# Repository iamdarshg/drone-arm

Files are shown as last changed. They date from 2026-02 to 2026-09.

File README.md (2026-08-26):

This is a codebase that is woring to create a hardware+software solution for dron control and management in a relatively modular manner. 
This is a codebase that is woring to create a hardware+software solution for dron control and management in a relatively modular manner.
This needs to be inherenly zero-trust, zero-fail and easy to analyse statically. The langauge of choice is C, with rust and python tooling accepted as well.Follow the 10 rules as set by nasa for code, the same should apply here due to the similar no-fail environment.
Currently, the main control board has been designed and the auxiallry field-oriented control esc needs to be designed.
Ideally, as much of this code as possible should be library free and written entirely from scratch. If any libraries are used beyond standard c libararies, they should all be stored within this folder, nowehere else.
Please add as much documentation as is needed, whenevr you refer to something just download and leave it in the docs folder. Please use the pico SDK exclusively as a library for C and/or write everything using reigster level functions.
Build will occur via Meson & Ninja. This means we will be compiling the whole thing using the arm toolchain, against the headers and flash tables and such from the SDK.
When debug is enabled in the meson build, we will output the assembly instead of the .uf2 file.

## Motor Platform (selected prototype baseline)

The ESC (Rev-B) is being optimized for the **Flycci FA4119 KV350** ([product page](https://robu.in/product/flycci-fpv-brushless-motors-fa4119-350kv/)). The current prototype decision, alternatives, cost model, proposed 550 Kv rewind, selected 8x4.5 propeller and mandatory validation gates are documented in [hardware/motor_release/FA4119_PROPULSION_DECISION.md](hardware/motor_release/FA4119_PROPULSION_DECISION.md).

- 12N14P outrunner (**7 pole pairs**), stator 41x19 mm, 280 g w/ cable
- Recommended 10S-12S LiPo, 13" prop, 80 A ESC class
- Measured (12S, HQ13x9-3 3-blade): 8.18 kg max thrust / 3.47 kW max @ 48 V, 74 A battery
- A rewind to **approximately 550 kV** is the experimental target if stock-motor dyno results justify it. The chosen Orange HD 8045 propeller has no verified manufacturer RPM rating in the repository, so the 550 Kv/12S combination requires closed-loop RPM limiting and guarded testing; it is not flight-released.

### eRPM headroom

eRPM = mech RPM x pole pairs (7). At 12S max (50.4 V):

| Winding | No-load RPM | No-load eRPM | Published or initially governed loaded eRPM |
|---|---|---|---|
| 350 kV (stock) | 17,640 | ~123 k | ~77-80 k with the manufacturer's 13-inch test prop |
| 550 kV (rewind) | 27,720 | ~194 k | initially <=91 k with the 8-inch prop (13,000 mechanical-rpm ceiling) |

**280 k eRPM check:** 280 k eRPM = 4.67 kHz electrical = 40,000 mechanical RPM at 7 pole pairs. This remains a possible future bare-rotor research point, not a propeller operating point. An 8-inch prop at 40,000 RPM has approximately 426 m/s rotational tip speed before pitch velocity and is unsuitable. The proposed 550 Kv winding reaches 194 k eRPM at fully charged 12S; initial propeller testing is capped at 13,000 mechanical RPM (91 k eRPM) pending a verified rating for the exact propeller.

## Build Instructions

This project uses Meson and Ninja for building.

### Prerequisites
- [ARM GNU Toolchain](https://developer.arm.com/Tools%20and%20Software/GNU%20Toolchain) (`arm-none-eabi-gcc`)
- [Meson](https://mesonbuild.com/)
- [Ninja](https://ninja-build.com/)
- Python 3

### Configuration
Create a build directory and configure the project:
```bash
meson setup build
```

To enable **Debug Mode** (includes assembly output and `-O0`):
```bash
meson setup build -Ddebug=enabled 
```

### Building
Build the firmware:
```bash
ninja -C build
```
This produces `firmware_main_board.uf2` and `firmware_esc_module.bin` in the `build` directory.

### Testing
To build and run the unit tests:
```bash
meson test -C build
```
Current tests include:
- `test_main`: Scheduler and basic async operations.
- `test_clock_safety`: (New) Integrity protection for global clock state.
The main software will run as two non-synchronised loops- the sensor loop and the PWM loop. The one loop will run at the speed of the ESCs and will provide the best estimate for what the thrust should be at any given time to the ESCs, 60Hz if communicating via PWM and 1 kHz if communicating via SPI. This rate will be configurable. This loop may also be offloaded to the PIO modules in the future. The other loop is reponsible for sensor measuerment and fusion.

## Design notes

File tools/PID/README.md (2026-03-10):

# PID Controller Design Tool — Documentation

## Overview

This tool implements industry-standard techniques for designing and tuning PID controllers for drone pitch control, using OpenMDAO for multidisciplinary optimization. The methodology mirrors practices at aerospace companies like NASA, Boeing, and Lockheed Martin.

**Location**: `tools/PID/`
**Main Script**: `main.py`

---

## Quick Start

```bash
# Install dependencies
pip install control openmdao matplotlib numpy

# Run PID design and optimization
python tools/PID/main.py
```

**Output Files**:
- `tools/PID/comparison_plots.png` — Bode, step response, Nyquist, pole-zero comparisons
- `tools/PID/optimization_history.png` — Convergence history plots

---

## Control Theory Background

### What is a Control System?

A control system makes a system's output follow a desired reference. For a drone, we want the pitch angle to track pilot commands:

```
Reference ──►[ PID Controller ]──►┬──►[ Drone Plant ]──► Output
                                   │
                                   ▼
                                -[ Feedback ]
                                   │
                                   └────────────►
```

Where:
- **Controller C(s)**: The PID controller (what we design)
- **Plant G(s)**: The drone pitch dynamics (physics we must work with)
- **Feedback**: The measured output compared to reference

### The PID Controller Math

A PID controller produces an output based on three terms:

```
u(t) = Kp·e(t) + Ki·∫e(τ)dτ + Kd·de/dt
```

In the Laplace domain (frequency domain), this becomes:

```
C(s) = Kp + Ki/s + Kd·s = (Kd·s² + Kp·s + Ki) / s
```

**Breaking down each term (intuitively)**:

| Term | Formula | Effect | Trade-off |
|---|---|---|---|
| **Proportional** | Kp·e(t) | Response proportional to current error | Fast but leaves steady-state offset |
| **Integral** | Ki·∫e(τ)dτ | Eliminates accumulated error | Removes offset but can cause overshoot |
| **Derivative** | Kd·de/dt | Responds to error rate of change | Adds damping, reduces overshoot, noise-sensitive |

### Drone Pitch Dynamics (The Plant)

Linearizing around hover, a quadrotor's pitch dynamics follow Euler's rotation equation:

```
Ixx·θ̈ + b_damp·θ̇ = τ
```

Where:
- `Ixx` = Moment of inertia about pitch axis (kg·m²)
- `b_damp` = Aerodynamic damping (N·m·s/rad)
- `τ` = Motor torque input

Taking the Laplace transform (zero initial conditions):

```
Ixx·s²·Θ(s) + b_damp·s·Θ(s) = T(s)
G(s) = Θ(s)/T(s) = 1 / (Ixx·s² + b_damp·s)
```

This is a **second-order system** with a pole at `s = 0` (integrator) and a pole at `s = -b_damp/Ixx` (damping).

### Closed-Loop Transfer Function

With unity feedback H(s) = 1:

```
T(s) = L(s) / (1 + L(s))   where   L(s) = C(s)·G(s)
```

The closed-loop transfer function describes how output responds to reference changes. The **poles** of T(s) (roots of the denominator) determine system behavior:
- Poles in left half-plane (LHP) = stable
- Distance from origin = speed (rise time)
- Angle from negative real axis = overshoot tendency

---

## Stability Analysis

### What Makes a System Stable?

A linear system is stable if all poles have negative real parts (left half of the complex plane). Unstable systems oscillate with growing amplitude.

### Gain Margin (GM)

**Definition**: How much the loop gain can increase before the system becomes unstable.

**How to find it**:
1. Find the **phase crossover frequency** ω_pc where phase of L(jω) = -180°
2. Measure gain at that frequency
3. GM = 1 / |L(jω_pc)|, expressed in dB

**Industry standard**: GM ≥ 6 dB for aerospace applications

### Phase Margin (PM)

**Definition**: How much phase lag can be added before instability.

**How to find it**:
1. Find the **gain crossover frequency** ω_gc where |L(jω)| = 1 (0 dB)
2. Measure phase at that frequency
3. PM = 180° + ∠L(jω_gc)

**Industry standard**: PM ≥ 45° for aerospace applications

### Intuition

Think of a swing:
- **Gain margin**: How much harder you can push before losing control
- **Phase margin**: How much delay you can tolerate before the swing goes chaotic

Both margins provide **robustness** against modeling errors and parameter variations.

---

## The Optimization Problem

Tuning PID gains manually is difficult. We formulate it as a **constrained optimization problem**:

### Design Variables
- Kp ∈ [0.1, 50]
- Ki ∈ [0, 20]
- Kd ∈ [0, 10]

### Objective Function
```
Minimize: J = settling_time + 0.05 × overshoot_pct
```

The weight 0.05 means "1% overshoot is worth 0.05s of settling time" — balancing speed and overshoot.

### Constraints
- **Gain Margin**: GM ≥ 6 dB (robustness requirement)
- **Phase Margin**: PM ≥ 45° (robustness requirement)

### Why OpenMDAO?

OpenMDAO is NASA's open-source MDO framework used throughout the aerospace industry:
- Handles constrained optimization with gradients
- Provides convergence analysis
- Separates analysis (control theory) from optimization (numerical methods)
- Industry-proven reliability

---

## Step Response Metrics

When we apply a step input (instantaneous reference change), the response tells us about controller performance:

| Metric | Definition | Typical Desired Value |
|---|---|---|
| **Rise Time** | Time from 10% to 90% of final value | Fast |
| **Settling Time** | Time to stay within 2% of final value | < 0.5s for drone pitch |
| **Overshoot** | How much response exceeds final value | < 10% typically |
| **Steady-State Error** | Final value minus reference | 0 (ideally) |

---

## File Structure

```
tools/PID/
├── README.md          # This file
├── main.py            # Main orchestrator, OpenMDAO component, plots
├── drone_model.py     # Drone pitch dynamics model
└── TODO.md            # Development notes
```

### `main.py` Components

1. **DronePitchModel** class: Pitch dynamics G(s) and PID controller C(s)
2. **PIDPerformanceComp**: OpenMDAO component computing metrics
3. **analyze_with_gains()**: Complete system analysis function
4. **plot_*** functions: Visualization of Bode, step, Nyquist, poles
5. **create_optimization_problem()**: OpenMDAO problem setup
6. **main()**: Orchestrator running the full workflow

### `drone_model.py` Components

1. **DronePitchModel** dataclass: Physical parameters (Ixx, b_damp)
2. Transfer function creation methods
3. Stability margin analysis
4. Step response metrics

---

## Troubleshooting

### Optimization Fails to Converge
- Initial gains may be in a poor region
- Try different initial values
- Check if constraints are too tight

### Gain/Phase Margins Show "inf"
- Phase never reaches -180° or gain never reaches 0 dB
- System is "very stable" in that sense
- Clamped to 60 dB / 90° in code

### Plots Show No Data
- Check matplotlib backend: `matplotlib.use('TkAgg')` if needed
- Ensure all dependencies installed

---

## References

1. **OpenMDAO Documentation**: https://openmdao.org/
2. **Python Control Library**: https://python-control.readthedocs.io/
3. **NASA MDO Practices**: https://ntrs.nasa.gov/api/citations/20180004467/downloads/20180004467.pdf

---

## Next Steps

To integrate with actual drone firmware:
1. Export optimized Kp, Ki, Kd values
2. Implement discrete-time PID in C (use bilinear/Tustin transform)
3. Add anti-windup logic for integral term
4. Test on hardware with safety limits

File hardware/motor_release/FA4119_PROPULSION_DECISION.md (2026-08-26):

# FA4119 Propulsion Decision Record

Status: **selected prototype baseline; not yet flight-released**

Decision date: 2026-08-26

Applies to: four-motor, 12S propulsion prototype

## 1. Decision

Use four Flycci FA4119 outrunners as the motor platform instead of manufacturing
the previously proposed stator, rotor bell, magnet carrier, shaft and bearing
system from first principles.

The purchased motor is the FA4119 KV350:

- 12 slots / 14 poles (7 pole pairs)
- 41 mm stator OD x 19 mm active stack
- approximately 50.5 mm motor OD x 44 mm height
- approximately 280 g including cable
- stock 350 rpm/V winding
- manufacturer recommendation: 10S-12S, 80 A ESC, 13-inch propeller
- manufacturer-published 12S-class point: approximately 3.47 kW, 74 A,
  11,256 rpm and 8.18 kgf using an HQ 13x9 three-blade propeller

The intended experimental variant is a **sensorless rewind to approximately
550 Kv**, operated from 12S with an Orange HD 8045 (8x4.5) CW/CCW propeller.
This combination is a development target, not a validated operating point.
The stock 350 Kv winding remains the lower-risk first-article baseline and
must be dyno-tested before a rewind is authorized for all four units.

No Hall-effect sensors are required. Rotor position is estimated by the ESC.

## 2. Requirements that drove the selection

The final system-level constraints used in this decision are:

| Requirement | Current value |
| --- | --- |
| Motors | 4 |
| Battery | 12S LiPo, 44.4 V nominal, 50.4 V fully charged |
| Desired nominal input per motor | approximately 2.7 kW |
| Desired current point | approximately 60 A at nominal 12S |
| Burst duration under discussion | up to 50 s at approximately 2.7 kW; requires test validation |
| Aircraft mass | approximately 8 kg |
| Desired total static thrust | aspirational 20 kgf; not yet demonstrated |
| Propeller packaging | ultimately moved from 5.5-7 inch concepts to an 8x4.5 candidate |
| Controller | sensorless FOC; current, RPM and temperature limiting required |

At nominal 12S, 60 A corresponds almost exactly to the desired input power:

```text
44.4 V x 60 A = 2.664 kW
```

At maximum charge, the same current is 3.024 kW. The FA4119's published
3.47 kW / 74 A test makes it the only retail candidate considered in this
thread with evidence near the required electrical power. That evidence does
not validate the rewind or the 8-inch propeller.

## 3. Alternatives considered

### 3.1 Fully custom 12-slot / 8-pole motor

The custom route evolved through several geometries, including a 42 mm stator
OD, approximately 20 mm stack, 62 mm motor OD, 45 mm height, 8 mm shaft,
retail block magnets, a formed 0.5 mm mild-steel flux liner, carbon/glass
retention, and machined 6061-T6 end components.

It was rejected as the primary prototype route because it required all of the
following to be solved simultaneously:

- retail electrical-steel or destructive donor-core sourcing
- lamination punching and interlaminar insulation
- a new high-speed rotor and magnet-retention system
- unverified retail magnet grade and temperature capability
- composite process qualification and rotor overspeed testing
- high-speed bearing qualification
- corrected manufacturing CAD, tolerance drawings and CNC quotations
- coupled electromagnetic, thermal, mechanical and harmonic validation

The custom artifacts remain useful research, but they are superseded for the
current prototype. They must not be mixed with the FA4119 BOM.

### 3.2 Three REES52 5010-class donors per motor

This route attempted to combine multiple inexpensive donor stacks to obtain
the desired active length. It required 12 donor motors for four propulsion
units and still retained a custom rotor, magnets, liner, shaft and end cap.
The material and integration cost approached that of a more suitable complete
motor while preserving most of the technical risk. It was rejected.

### 3.3 Axisflying AZ3115/AZ3215 900 Kv

Advantages:

- approximately 900 Kv already close to the earlier 800-840 Kv target
- comparatively inexpensive
- no major rewind needed for that Kv region

Reasons rejected for the final 12S platform:

- nominally a 3S-6S motor
- published power approximately 1.6-1.74 kW, below the 2.7 kW target
- published thrust approximately 4.1 kgf with a much larger 9-10 inch prop
- stock rotor not qualified for 12S no-load speed

### 3.4 Tarot 5008 340 Kv

The Tarot has a large diameter but only an approximately 8 mm active stack and
about a 700 W published power level. Raising it from 340 Kv to the earlier
800 Kv target would require a severe turn-count reduction while retaining a
core designed for low-speed 17-18 inch props. It was rejected.

### 3.5 Flycci FA4119 350 Kv

Selected because its 41x19 mm stator is almost exactly the desired compact
core, the complete motor fits the 62 mm OD / 45 mm height packaging envelope,
and its published 12S test exceeds the desired per-motor power. Buying the
complete motor removes the need to fabricate the rotor, back iron, magnets,
shaft, bearing system and housing for the first prototype.

## 4. Why the topology is now 12N14P

The selected motor is 12-slot / 14-pole. Rewinding changes turns, conductor
area, resistance, inductance, termination and Kv; it does **not** change rotor
pole count. Converting the FA4119 to the previously discussed 8-pole topology
would require a new rotor and would defeat most of the reason for selecting a
complete retail motor.

For this release:

```text
pole pairs = 14 / 2 = 7
electrical RPM = mechanical RPM x 7
electrical frequency (Hz) = mechanical RPM x 7 / 60
```

## 5. Winding decision

### 5.1 Stock first article

Purchase one FA4119 first and record, before destructive unwinding:

1. Stock no-load Kv at a safe low voltage.
2. No-load current versus speed.
3. Line-to-line resistance corrected to 25 C.
4. Line-to-line inductance at 1 kHz and 10 kHz.
5. Star or delta termination.
6. Turns per tooth, winding direction and phase sequence.
7. Strand count and bare/enamelled strand diameter.
8. Removed copper mass and usable slot fill.
9. Back-EMF waveform and phase balance.

The other three motors must not be unwound until the first article produces a
repeatable winding and passes the guarded dyno sequence.

### 5.2 Nominal 550 Kv target

If magnetic flux and termination are unchanged, turns scale approximately
inversely with Kv:

```text
N_550 / N_350 = 350 / 550 = 0.636
```

The 550 Kv winding therefore requires approximately 63.6% of the stock
effective series turns. Integer turns determine the actual Kv, so 550 is a
target, not a value to print on the motor before spin measurement.

If the stock winding is star-connected, a star/delta change alters Kv by
approximately sqrt(3) and must be included before choosing the turn count.
The freed slot area must be used for additional parallel copper so that phase
resistance and current density remain controlled.

Only Class-H or better enamelled winding copper is acceptable. Nomex slot
liners and compatible impregnation varnish remain in the rewind BOM. Building
wire, speaker wire, bare copper strips with many joints, and PVC/nylon-insulated
conductors are not approved winding substitutes.

## 6. 12S speed envelope

The theoretical no-load values are:

| Winding | 44.4 V nominal | 50.4 V maximum | Maximum no-load eRPM |
| --- | ---: | ---: | ---: |
| Stock 350 Kv | 15,540 rpm | 17,640 rpm | 123,480 eRPM |
| Proposed 550 Kv | 24,420 rpm | 27,720 rpm | 194,040 eRPM |

The earlier 40,000 mechanical-rpm discussion corresponds to 280,000 eRPM and
4.67 kHz electrical frequency. It may be retained as a future bare-rotor
research point, but it is not an operating target for an 8-inch propeller.

## 7. Selected propeller and unresolved rating

Candidate: Orange HD 8045, 8x4.5, one CW and one CCW per pair:

<https://robu.in/product/orange-hd-propellers-80458x4-5-carbon-fiber-props-1cw1ccw-1pair-black/>

The retail title calls it carbon fibre, while comparable listings describe an
8045 carbon-nylon propeller. No manufacturer-issued maximum-RPM certificate
for the exact item was found. It must therefore be treated as an **unrated
multirotor propeller**, not as a continuous-laminate carbon racing propeller.

For reference, APC's published category limits are:

```text
multirotor: 105,000 / diameter_in = 13,125 rpm for 8 inches
durable FPV: 150,000 / diameter_in = 18,750 rpm for 8 inches
racing electric: 270,000 / diameter_in = 33,750 rpm for 8 inches
```

These formulas apply to APC's own qualified categories and do not certify the
Orange prop. Until written evidence is obtained, the initial hard ceiling is
13,000 mechanical rpm.

Eight-inch rotational tip speeds are:

| Speed | Tip speed | Approximate Mach at sea level |
| --- | ---: | ---: |
| 13,000 rpm | 138 m/s | 0.40 |
| 17,640 rpm | 188 m/s | 0.55 |
| 18,750 rpm | 199 m/s | 0.58 |
| 27,720 rpm | 295 m/s | 0.86 |
| 40,000 rpm | 426 m/s | 1.24 |

The values exclude axial/pitch velocity. Unrestricted 550 Kv operation on a
fully charged 12S pack is therefore not approved with this propeller.

## 8. Required controller limits

A throttle percentage limit alone is not sufficient because an unloading,
damaged or detached propeller lets the motor accelerate toward no-load speed.
The sensorless FOC controller must use measured/estimated RPM plus current and
temperature feedback.

Initial first-article limits:

| Limit | Initial value |
| --- | ---: |
| Soft RPM rollback | 12,500 mechanical rpm |
| Hard RPM shutdown | 13,500 mechanical rpm |
| Soft battery-current rollback | 55 A |
| Hard battery-current limit | 60-65 A |
| Winding-temperature rollback | 100-110 C |
| Winding-temperature shutdown | 120 C during development |
| Bell/magnet-region warning | 70 C |
| Bell/magnet-region shutdown | 80 C pending magnet/adhesive data |

Only after the exact propeller obtains a suitable rating and guarded dyno
testing passes may a second profile be considered:

| Limit | Provisional upper profile |
| --- | ---: |
| Soft RPM rollback | 17,000 mechanical rpm |
| Hard RPM shutdown | 18,000 mechanical rpm |
| Nominal current limit | 60 A |
| Short overcurrent ceiling | 70-75 A, subject to thermal data |

The ESC must support at least 200,000 eRPM with margin, 12S maximum voltage,
sensorless FOC, RPM telemetry/governing, current limiting and thermal rollback.

## 9. Cost decision for four motors

Confirmed motor price: INR 4,500 each.

| Item | Four-motor estimate |
| --- | ---: |
| Four FA4119 motors | INR 18,000 |
| Rewind copper, Nomex, varnish, thermistors and small consumables | approximately INR 7,000 |
| Motor plus rewind subtotal | **approximately INR 25,000** |
| Previously selected composite order | INR 4,271 |
| Vacuum pump for infusion | INR 6,800 |
| Motor, rewind, composite order and pump | **approximately INR 36,071** |

Two propeller pairs, ESCs, shipping, taxes not included in the confirmed motor
price, and replacement test articles must be added. If the stock 350 Kv
winding is retained, approximately INR 6,900 of rewind materials can initially
be deferred.

The FA4119 path removes these custom-motor purchases from the active BOM:

- separate rotor magnets
- formed mild-steel rotor liner
- custom rotor carbon/glass sleeve
- custom 6061 rotor end cap and stator carrier
- separate 8 mm shaft stock
- separate 608 bearings
- Hall-effect sensors
- donor motors or donor laminations

## 10. Verification and release gates

No claimed thrust, aircraft speed, efficiency or 50-second burst value is a
release fact until measured with the exact winding and propeller.

The minimum sequence is:

1. Characterize one untouched stock motor.
2. Balance the stock bell and each propeller independently.
3. Dyno the stock 350 Kv motor with the selected prop behind containment.
4. Test at 8,000, 10,000, 12,000 and 13,000 rpm while logging voltage,
   current, input power, RPM, thrust, torque, winding temperature, bell
   temperature, ESC temperature and vibration.
5. Inspect the prop hub, blades, shaft, bell, magnets and bearings after every
   step.
6. If the stock configuration cannot meet the measured aircraft requirement,
   rewind only the first article to the calculated 550 Kv winding.
7. Measure actual Kv, resistance, inductance, no-load current and phase balance.
8. Repeat the guarded propeller ladder at the initial limits.
9. Run 2-minute thermal characterization at lower current before attempting
   the requested 50-second 2.7 kW burst.
10. Perform a propeller-free overspeed test in a rated containment fixture;
    do not infer rotor proof from a propeller test.
11. Freeze winding turns/strand count only after two repeat builds correlate.
12. Flight release requires four matched motors and props plus aircraft-level
    loss-of-prop, ESC fault, vibration and EMI testing.

## 11. Superseded documents

The following release-package files describe an older custom motor and remain
only for traceability:

- `MOTOR_SPECIFICATION.md`
- `materials.md`
- `magnet_specification.md`
- `bearing_specification.md`
- `tolerances.md`
- custom STEP, DXF, drawing, winding and optimizer artifacts in this directory
- `FINAL_BOM_4_MOTORS_EXCL_STATOR_CORE.md` and its CSV counterpart

They are not manufacturing instructions for the FA4119 prototype. This
decision record is the current propulsion baseline until measured first-article
data supports a revised release.

## 12. External references

- Flycci FA4119 manufacturer data:
  <https://www.flyccimotor.com/fa4119-brushless-motor-product/>
- Robu FA4119 retail listing:
  <https://robu.in/product/flycci-fpv-brushless-motors-fa4119-350kv/>
- Selected Orange HD 8045 retail listing:
  <https://robu.in/product/orange-hd-propellers-80458x4-5-carbon-fiber-props-1cw1ccw-1pair-black/>
- APC category RPM limits used only as reference:
  <https://www.apcprop.com/technical-information/rpm-limits/>

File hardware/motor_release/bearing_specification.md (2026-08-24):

# Bearing Specification

## Arrangement

- Front (prop end): **6901-2RS** thin-section deep groove, 12x24x6 mm, radially supports the prop overhung load and all axial thrust.
- Rear: **685-2RS** extra-thin-section, 5x11x3 mm (or 688 if shaft stiffness review requires), locates the rotor axially at the cold end.
- Both bearings pressed onto ground shaft seats and clamped in machined aluminum housings with a light axial preload wave washer at the rear.

## Loads and life

| Load case | Front bearing | Rear bearing |
| --- | --- | --- |
| Prop thrust 45 N axial | carries fully | negligible |
| Rotor weight plus 1g maneuver ~10 N radial | majority | remainder |
| Residual unbalanced magnetic pull (10% of mean gap attraction) | shared by span | shared by span |

L10 basic rating life target: at least 2000 h at design point loads and 13,300 rpm.
Grease: high-speed synthetic polyurea or ester, suitable to 25,000 rpm DN
envelope. -2RS contact seals retained; shielded (-ZZ) alternate only with a
manufacturer-approved relubrication plan.

## Installation

- Shaft seat tolerances per tolerances.md; housing bores H7.
- Assembly by pressing on the inner ring only; never transmit force through balls.
- Maximum assembly heating temperature for bearings: 110 C.

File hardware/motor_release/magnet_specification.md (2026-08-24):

# Permanent Magnet Specification

## Grade and geometry

- Material: sintered NdFeB, grade **N42SH** (Br = 1.24-1.30 T design window; the optimizer used 1.244 T)
- SH temperature class: max continuous operating temperature 150 C, with intrinsic coercivity Hcj >= 20 kOe retained to that temperature
- Magnet radial thickness: 6.5 mm
- Pole count: 8 (arc-pitched to give approximately 0.85 pole arc to pole pitch ratio)
- Axial length: 56.0 mm (matches stator stack)

## Thermal and demagnetization verification

- Continuous thermal FEM gives magnet-region temperature <= 113.5 C at 45 C ambient with 60 A continuous: 36.5 C of margin to the SH 150 C limit.
- Burst case (90 A / 30 s) transient adds under 15 C: still at least 20 C of margin.
- Demagnetization check: peak armature reaction at 90 A burst keeps the operating point above the knee for N42SH at 130 C; manufacturer to confirm with FEA of the final magnet shape.

## Retention

1. Bond line: structural epoxy, 0.10 mm nominal, cured per adhesive datasheet.
2. Mechanical backup: 0.5 mm minimum steel retaining ring or bell lip crimp designed for hoop stress at 16,659 rpm proof speed with safety factor >= 2 against ring yield.
3. Balance: rotor assembly balanced to ISO 21940 G6.3 after magnet installation.

## Acceptance

- Each magnet batch certified for Br, Hcj, and SH-class temperature coefficient.
- Sample pull test: bond plus retention system survives 1000x centrifugal equivalent acceleration at room temperature on a spin fixture.

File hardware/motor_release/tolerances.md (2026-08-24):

# Tolerances And Critical Fits

## General

- Unspecified dimensions: ISO 2768-m (medium).
- All rotating parts balanced after final assembly: ISO 21940 G6.3 at rated speed.

## Critical fits

| Feature | Fit / tolerance | Rationale |
| --- | --- | --- |
| Stator OD to housing bore | H7/g6 press with adhesive | heat transfer and torque reaction |
| Lamination stack length | 56.0 (+0.3 / -0.0) mm | axial magnet-stator alignment |
| Bearing shaft seats | k5 | standard rotating inner ring fit |
| Bearing housing bores | H7 | outer ring clearance fit with clamp |
| Prop adapter thread | M8x1.25 6H/6g, or per prop spec | clamped, not keyed |
| Shaft runout at prop seat | <= 0.02 mm TIR | vibration limit |
| Air gap (nominal 0.50 mm) | concentricity budget keeps local gap >= 0.35 mm | avoids pull-in under UMP |
| Magnet pocket depth | 6.5 (+0.05/-0.0) mm | bond line control |
| Magnet-to-magnet circumferential pitch | +/- 0.15 mm at rotor OD | cogging and balance |

## Thermal growth verification

At continuous rating the optimizer's expansion model predicts rotor growth of
about 0.07 mm radially at operating temperature. The 0.35 mm minimum local gap
budget above already includes this case plus bearing radial clearance.

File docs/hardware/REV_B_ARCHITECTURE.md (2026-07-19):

# Hardware revision B architecture

Revision B is a new, distinct ESC and flight-control implementation. It does
not overwrite or silently approve the original hardware. The generated
projects are:

- `hardware/esc/rev_b/esc_rev_b.kicad_sch` and
  `hardware/esc/rev_b/esc_rev_b.kicad_pcb`
- `hardware/main/rev_b/main_rev_b.kicad_sch` and
  `hardware/main/rev_b/main_rev_b.kicad_pcb`

## Design basis

| Item | Revision B basis |
| --- | --- |
| Battery | 12S LiPo, 50.4 V maximum charged voltage |
| Motors | Six independent three-phase BLDC/PMSM channels |
| Current | 60 A continuous design current per motor channel |
| Aggregate | 360 A maximum, distributed by six external fused star/busbar taps; never by a shared PCB trunk |
| ESC stack | Four layers: 4 oz F.Cu/B.Cu and 1.5 oz In1.Cu/In2.Cu |
| Initial PWM | 20 kHz, to be finalized by switching-loss, acoustic, and control-loop tests |
| Safe state | Every gate off until both central and local hardware/firmware permissions are valid |

A battery above 12S is a major architecture change. The 100 V MOSFET, 100 V
gate driver, TVS selection, DC-link capacitors, dividers, creepage, and
switching-overshoot margin must all be redesigned for it.

## Why local motor controllers are required

The six battery returns are independent high-current nodes. Millivolt shunt
signals, single-ended PWM, or SPI cannot be carried between those nodes and a
central digital ground without creating measurement error and unintended
return-current paths.

Revision B therefore contains six electrically partitioned motor cells. Each
cell is referenced only to its own `M<n>_BATN` and contains:

- one STM32G431CBT6 motor-control MCU;
- one DRV8353S three-phase gate driver;
- six IPTC014N10NM5 100 V TOLT MOSFETs;
- three 0.5 mOhm four-terminal low-side phase-leg shunts;
- one separate 0.5 mOhm four-terminal high-side DC-input shunt;
- an INA296A2 bidirectional high-side bus-current amplifier;
- local DC-link capacitance, TVS, temperature sensing, and SWD;
- an ISO6731F fail-low command/arm/status interface; and
- an RFM-0505S functional-isolation converter followed by a TPS70933 LDO.

The central RP2354B on the ESC is a supervisor and communications processor.
It does not generate phase PWM and it does not acquire remote analog shunts.
Each motor MCU performs FOC locally and receives torque/thrust commands over
an isolated UART channel.

## High-speed current acquisition

Every motor has four high-speed current observables:

1. phase-leg A current from DRV8353S CSA A;
2. phase-leg B current from DRV8353S CSA B;
3. phase-leg C current from DRV8353S CSA C; and
4. bidirectional DC-input current from INA296A2.

All four outputs terminate at the local STM32G431 ADC pins. The MCU has two
4 MSPS ADCs with timer-triggered injected conversions. ADC2 sequences phase A
and phase B while ADC1 sequences phase C and bus current. Both two-channel
sequences are launched from the same center-aligned PWM event and complete in
about 0.5 us at the maximum ADC clock. The four channels are therefore
sampled once per PWM period with bounded sub-microsecond skew; this is not a
claim that four independent sample/hold circuits capture at exactly the same
instant.

Each output has a 47 ohm/10 nF C0G filter (approximately 339 kHz pole). The
filter is fast enough for cycle-by-cycle control and fault telemetry while
attenuating switching edges. The DRV8353 CSAs and bus amplifier use a 1.65 V
reference:

- shunt: 0.5 mOhm;
- CSA and INA296A2 gain: 20 V/V;
- scale: 10 mV/A;
- 60 A signal: 0.6 V from midscale;
- approximate linear range with 0.25-3.05 V ADC guard limits: +/-140 A; and
- 60 A shunt dissipation: 1.8 W.

The three phase-shunt force paths and their Kelvin sense pads are separate in
the footprint and netlist. Sense traces are routed as quiet pairs and are not
allowed to share load-current copper after the Kelvin pickup.

## PWM and hardware shutdown

The local STM32 uses TIM1 complementary outputs:

| Function | STM32 pin |
| --- | --- |
| AH/BH/CH | PA8 / PA9 / PA10 |
| AL/BL/CL | PB13 / PB14 / PB15 |
| Driver fault break | PA11 / TIM1_BKIN2 |

TIM1 inserts hardware dead time. DRV8353S `nFAULT` drives the timer break
input, so a driver fault stops PWM without waiting for firmware. Driver
`ENABLE` is the output of a hardware AND gate:

`ENABLE = isolated central ARM_SAFE AND local MCU_ARM`

All three signals have fail-low pull-downs. ISO6731F fail-low behavior, the
central TPS3430 watchdog, the local timer break, and the local command timeout
are independent shutdown layers.

An external gate-drive booster is not fitted. DRV8353S already provides
programmable source/sink current, VDS protection, three CSAs, SPI diagnostics,
and matched high/low propagation. Adding six floating booster supplies and
twelve discrete buffers per bridge would increase loop area and delay spread.
The selected MOSFET has 168 nC typical and 211 nC maximum total gate charge at
the datasheet test point. The PCB places every 2.2 ohm series resistor about
4.1 mm from its TOLT gate; the longest driver-to-resistor air-line is about
27.2 mm before detailed routing. A booster is reconsidered only if measured
double-pulse data shows that the selected IDRIVE setting cannot meet the
switching-loss/overshoot target.

## Power and isolation

The RFM-0505S is an unregulated 1 W functional-isolation module. Its output is
not connected directly to 3.3 V logic: a 30 V-input TPS70933 absorbs the
module's light-load tolerance. TPS709 `EN`, which has a lower absolute maximum
than `IN`, is driven by a local 100 kohm/68 kohm divider rather than by the raw
converter output. This is functional isolation for motor-return offset/noise
containment, not a human-safety isolation barrier.

The ESC auxiliary supply uses two independent LM5164 1 A buck rails:

- one 5 V rail for the ESC supervisor and six isolation-module primary sides;
- one fused 5 V rail exported to the flight-control board.

This removes the marginal loading of a single shared 1 A rail and makes a
flight-board short incapable of brownout-resetting the motor cells.

## ESC current-path layout rules

- Six independent M5 battery inputs are mandatory. No 360 A copper trunk is
  present on the ESC PCB.
- The high-current cells are physically partitioned and no `BATN` domains are
  joined.
- Major 60 A paths use copper areas, 4 oz outer copper, inner-layer
  reinforcement where switching-node geometry permits it, and calculated via
  fields.
- The commutation loop is local to each half bridge and its DC-link
  capacitors.
- The F.Cu switch-node copper is split into small MOSFET landing islands.
  In2 carries the phase to the motor lug and leaves a clear F.Cu corridor for
  paired gate/source routing.
- No reference plane is placed directly under a switching node outside its
  local half-bridge region.
- Gate-drive loops are short, do not share load-current copper, and return to
  the corresponding source.
- The bus and phase Kelvin pairs stay inside the quiet analog/control area.
- TOLT tops require an electrically isolated, mechanically controlled heat
  spreader. The headline MOSFET current rating is not a thermal qualification.

Each cell uses an SM8S51A transient clamp: 51 V standoff, 56.7 V minimum
breakdown, and 82.4 V maximum specified clamp. This improves margin to the
100 V MOSFET limit compared with the earlier 54 V part. It is a pulse clamp,
not a dump load; firmware must limit regeneration and the connected battery
must be capable of accepting the returned energy.

The present PCB outline is intentionally large because the inputs are treated
as six continuous 60 A channels rather than a burst-current marketing rating.
Reducing the outline requires a documented duty cycle, lower current, a
different mechanical busbar/heatsink assembly, or separate per-motor modules.

## ESC-to-flight-control link

Both boards use an MCP2518FD SPI CAN-FD controller and a TCAN3413 3.3 V
transceiver because RP2354B has no native CAN controller. The connector
carries fused 5 V, CAN ground, CANH, and CANL. A common-mode choke,
PESD2CANFD24L-T protection, and an optional 120 ohm terminator are local to
each interface.

The flight-control board remains electrically and physically distinct from
the ESC. It sends torque/thrust requests and receives telemetry; it never
sends raw gate patterns.

## Flight-control corrections

- Real USB-C USB 2.0 connector, 5.1 kohm CC pull-downs, and USB ESD protection.
- RP2354B supply pins and internal switcher network follow the RP2350 hardware
  guide; GPIOs are no longer tied to unrelated supply rails.
- Two dissimilar IMUs and the barometer are retained for fault detection.
- GNSS uses a dedicated UART, local 2.8 V/3.3 V quiet LDOs, an always-on
  backup rail, and a U.FL antenna connection.
- The 915 MHz network uses fixed CC1121/CC1190 reference values, U.FL, a
  continuous RF reference plane, local decoupling/matching placement, and a
  via-fenced RF region. Final matching still requires VNA verification on the
  assembled stackup.
- CAN FD replaces high-current or analog signals on the inter-board cable.

## Required physical validation

Passing ERC, netlist checks, and PCB DRC is necessary but cannot prove a
360 A electromechanical assembly safe. Fabrication release still requires:

1. independent symbol/footprint pin audit;
2. impedance and DC-resistance review against the fabricator's actual stack;
3. one-channel current-limited bring-up;
4. double-pulse switching and overshoot measurements;
5. calibrated shunt/ADC gain, offset, and timing tests;
6. thermal soak at 60 A with the production heat spreader and airflow;
7. regenerative braking and bus-disconnect testing;
8. locked-rotor, phase-open, phase-short, command-loss, and watchdog tests;
9. conducted/radiated EMI testing with GNSS and RF active; and
10. VNA tuning plus regional radio regulatory verification.

Firmware release also requires read-back verification of the DRV8353 SPI
configuration: 6x PWM mode, bidirectional CSA reference, 20 V/V CSA gain,
COAST/BRAKE inactive, conservative IDRIVE/tDRIVE/dead-time/VDS thresholds, and
clean fault registers before `MCU_ARM` may assert.

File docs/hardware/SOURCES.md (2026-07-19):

# Hardware validation sources

Primary manufacturer documents used for the review are listed below. Most are
mirrored under `docs/datasheets` and `docs/reference-designs`; the listed
manufacturer URL remains authoritative and should be checked for a newer
revision before a production spin.

## Motor cell and current acquisition

| Local file | Primary source |
| --- | --- |
| `docs/datasheets/esc/ti-drv8353.pdf` | https://www.ti.com/lit/ds/symlink/drv8353.pdf |
| `docs/datasheets/esc/infineon-iptc014n10nm5.pdf` | https://www.infineon.com/assets/row/public/documents/24/49/infineon-iptc014n10nm5-datasheet-en.pdf |
| `docs/datasheets/esc/bourns-css4j-4026.pdf` | https://www.bourns.com/docs/product-datasheets/css4j-4026.pdf |
| `docs/datasheets/esc/ti-ina296a.pdf` | https://www.ti.com/lit/ds/symlink/ina296a.pdf |
| `docs/datasheets/esc/st-stm32g431cb.pdf` | https://www.st.com/resource/en/datasheet/stm32g431cb.pdf |
| `docs/reference-designs/esc/st-an5093-stm32g4-hardware.pdf` | https://www.st.com/resource/en/application_note/an5093-getting-started-with-stm32g4-series-hardware-development-stmicroelectronics.pdf |
| `docs/datasheets/esc/ti-iso6731.pdf` | https://www.ti.com/lit/ds/symlink/iso6731.pdf |
| `docs/datasheets/esc/recom-rfm.pdf` | https://recom-power.com/pdf/Econoline/RFM.pdf |
| `docs/datasheets/esc/ti-tps709.pdf` | https://www.ti.com/lit/ds/symlink/tps709.pdf |
| `docs/datasheets/esc/littelfuse-sm8s.pdf` | https://www.littelfuse.com/assetdocs/littelfuse-tvs-diode-sm8s-datasheet |
| `docs/reference-designs/esc/infineon-eval-tolt-dc48v-3kw.pdf` | https://www.infineon.com/assets/row/public/documents/24/44/infineon-evaluation-board-eval-tolt-dc48v-3kw-usermanual-en.pdf |
| `docs/reference-designs/esc/ti-motor-driver-layout.pdf` | https://www.ti.com/lit/an/slva959b/slva959b.pdf |

## ESC auxiliary power and supervision

| Local file | Primary source |
| --- | --- |
| `docs/datasheets/esc/ti-lm5164.pdf` | https://www.ti.com/lit/ds/symlink/lm5164.pdf |
| `docs/datasheets/esc/ti-tps3430.pdf` | https://www.ti.com/lit/ds/symlink/tps3430.pdf |
| `docs/datasheets/esc/diodes-ap2112.pdf` | https://www.diodes.com/assets/Datasheets/AP2112.pdf |
| `docs/datasheets/esc/ti-sn74lvc1g08.pdf` | https://www.ti.com/lit/ds/symlink/sn74lvc1g08.pdf |

## CAN FD on both boards

| Local file | Primary source |
| --- | --- |
| `docs/datasheets/common-microchip-mcp2518fd.pdf` | https://ww1.microchip.com/downloads/en/DeviceDoc/External-CAN-FD-Controller-with-SPI-Interface-DS20006027B.pdf |
| `docs/datasheets/common-ti-tcan3413.pdf` | https://www.ti.com/lit/ds/symlink/tcan3413.pdf |
| `docs/datasheets/common-nexperia-pesd2canfd24l-t.pdf` | https://assets.nexperia.com/documents/data-sheet/PESD2CANFD24L-T.pdf |

## Flight-control MCU, USB, sensors, and GNSS

| Local file | Primary source |
| --- | --- |
| `docs/datasheets/main/rp2350-datasheet.pdf` | https://datasheets.raspberrypi.com/rp2350/rp2350-datasheet.pdf |
| `docs/datasheets/main/rp2350-hardware-design.pdf` | https://datasheets.raspberrypi.com/rp2350/hardware-design-with-rp2350.pdf |
| `docs/datasheets/main/ti-tlv62569.pdf` | https://www.ti.com/lit/ds/symlink/tlv62569.pdf |
| `docs/datasheets/main/ti-tlv755p.pdf` | https://www.ti.com/lit/ds/symlink/tlv755p.pdf |
| `docs/datasheets/main/tdk-icm42688p.pdf` | https://invensense.tdk.com/wp-content/uploads/2020/04/ds-000347_icm-42688-p-datasheet.pdf |
| `docs/datasheets/main/st-lsm6dso32.pdf` | https://www.st.com/resource/en/datasheet/lsm6dso32.pdf |
| `docs/datasheets/main/st-lps22df.pdf` | https://www.st.com/resource/en/datasheet/lps22df.pdf |
| `docs/datasheets/main/quectel-lg77l-hardware-design.pdf` | https://forums.quectel.com/uploads/short-url/9zAmjO9mANigfC05VclI7cICxed.pdf |

## 915 MHz radio

| Local file | Primary source |
| --- | --- |
| `docs/datasheets/main/ti-cc1121.pdf` | https://www.ti.com/lit/ds/symlink/cc1121.pdf |
| `docs/datasheets/main/ti-cc1190.pdf` | https://www.ti.com/lit/ds/symlink/cc1190.pdf |
| `docs/reference-designs/main/ti-swrc224.zip` | https://www.ti.com/lit/zip/swrc224 |
| `docs/reference-designs/main/ti-swrr145a.zip` | https://www.ti.com/lit/zip/swrr145 |
| `docs/reference-designs/main/ti-cc112x-cc1190-boosterpack.pdf` | https://www.ti.com/lit/an/swra492/swra492.pdf |

TI explicitly recommends following the characterized CC112x/CC1190 reference
layout. The checked-in component values and placement are therefore only the
starting point: the production stackup requires VNA tuning and conducted/
radiated compliance testing.

## Legacy documents retained for the failure audit

| Local file | Primary source |
| --- | --- |
| `docs/datasheets/esc/infineon-ir2136.pdf` | https://www.infineon.com/assets/row/public/documents/24/49/infineon-ir213-ds-en.pdf |
| `docs/datasheets/esc/ti-ina240.pdf` | https://www.ti.com/lit/ds/symlink/ina240.pdf |
| `docs/datasheets/esc/ti-tla2528.pdf` | https://www.ti.com/lit/ds/symlink/tla2528.pdf |
| `docs/datasheets/esc/nexperia-buk9k12-80l.pdf` | https://assets.nexperia.com/documents/data-sheet/BUK9K12-80L.pdf |
| `docs/datasheets/esc/ti-lm5148-q1.pdf` | https://www.ti.com/lit/ds/symlink/lm5148-q1.pdf |
| `docs/datasheets/esc/infineon-iptc015n10nm5.pdf` | https://www.infineon.com/dgdl/Infineon-IPTC015N10NM5-DataSheet-v02_00-EN.pdf |

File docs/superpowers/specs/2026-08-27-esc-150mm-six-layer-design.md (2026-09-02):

# 150 mm Six-Layer ESC Physical Design

## Scope

Replace only `hardware/esc/rev_b/esc_rev_b.kicad_pcb` with a deterministic placement candidate generated from the existing validated Rev-B ESC netlist. Preserve the schematic, all electrical footprints, reference designators, pad-to-net assignments, and the separate flight-control PCB.

## Mechanical architecture

The PCB outline is a closed 150.00 mm by 150.00 mm square. Six motor cells occupy a 3-by-2 matrix. Each cell owns a 48 mm by 55 mm placement grid; motor cells 1-3 occupy the upper row and 4-6 the lower row. Shared auxiliary power and supervisor components occupy dedicated horizontal grids outside the motor grids. Mounting holes remain inside a 4 mm edge inset and must not overlap electrical courtyards.

Every electrical footprint must be fully inside the outline. High-current and gate-loop parts remain on F.Cu; low-power local control and support parts may be placed on B.Cu within the same owning motor grid. Grid membership is derived from the component sheet and the existing motor-numbered reference blocks. The generator must fail instead of silently placing a footprint outside its assigned grid.

## Six-layer stack

The copper layers are F.Cu, In1.Cu, In2.Cu, In3.Cu, In4.Cu, and B.Cu in a nominal 1.6 mm stack. F.Cu hosts all components, local switching copper, gate loops, and Kelvin pickups. In1.Cu is the quiet/local return reference. In2.Cu carries reinforced BAT+ distribution. In3.Cu carries reinforced BAT- distribution. In4.Cu is reserved for low-current control and telemetry routing. B.Cu provides local thermal spreading and reinforced power return. Final dielectric and copper thicknesses require fabricator field solving and thermal review.

Switch-node copper stays local to each motor cell. No global phase plane is permitted. BAT+ and BAT- reinforcement may be shared only through intentional star/bus regions and must retain isolation from quiet references.

## Placement strategy

Each motor grid places its three half bridges, gate driver, gate resistors, current shunts, and local DC-link components on F.Cu. Motor terminals, isolated control, local MCU, current-sense support, and remaining passives use a deterministic B.Cu grid where necessary. Remaining components are packed deterministically using courtyard-aware rectangle packing. Support parts cannot cross a cell boundary.

The top shared grid contains battery input/protection and auxiliary supplies. The center/shared corridor contains supervisor, ADC, CAN-FD, and isolated-control components. Connectors that require physical access are placed on board edges.

## Generated-board gates

The generation stage is successful only when all of these are true:

- outline bounding box is exactly 150.00 mm by 150.00 mm;
- copper-layer count is exactly six;
- all schematic-derived electrical footprints are present exactly once;
- every footprint is fully inside the board and assigned to an intentional side;
- each motor-numbered footprint anchor is inside its assigned grid; courtyard boundary bleed is reported separately and must be resolved before fabrication routing;
- no courtyard overlap exists between different motor grids;
- KiCad accepts the PCB and reports no malformed outline;
- a placement audit records grid bounds, populations, and failures.

Routing, zero-open DRC, continuous 60 A operation, aggregate 360 A operation, busbar design, heatsinking, double-pulse behavior, and thermal qualification are downstream gates. Passing placement does not establish those ratings.

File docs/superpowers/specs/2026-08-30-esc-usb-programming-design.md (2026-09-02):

# ESC USB-C Programming Architecture

Date: 2026-08-30

## Objective

Add USB programming access to every programmable domain on the Rev-B six-channel ESC while preserving galvanic separation between the controller domain and the six motor-cell domains. Remove the six on-PCB bulk capacitors that are physically external to the PCB from the authoritative schematic and PCB/netlist contract.

## Existing programmable domains

The ESC has seven programmable MCUs:

- Controller domain: `U201`, RP2354B, with native USB on pins 66 `USB_DM` and 67 `USB_DP`.
- Motor cell 1: `U1102`, STM32G431CBT6, native USB FS on PA11/PA12.
- Motor cell 2: `U1202`, STM32G431CBT6, native USB FS on PA11/PA12.
- Motor cell 3: `U1302`, STM32G431CBT6, native USB FS on PA11/PA12.
- Motor cell 4: `U1402`, STM32G431CBT6, native USB FS on PA11/PA12.
- Motor cell 5: `U1502`, STM32G431CBT6, native USB FS on PA11/PA12.
- Motor cell 6: `U1602`, STM32G431CBT6, native USB FS on PA11/PA12.

The six motor cells are separate electrical domains. A programming interface must never bond two cell returns together or bond a cell return permanently to controller ground.

## External bulk capacitors

Remove `C1130`, `C1230`, `C1330`, `C1430`, `C1530`, and `C1630` from the six motor-cell schematics and from generated PCB/netlist expectations. Their BATP/BATN connections remain documented as external wiring requirements rather than PCB components.

The schematic notes for each motor cell shall state that the external bulk capacitor is connected directly across that cell's BATP/BATN power leads with the shortest practical high-current loop. No replacement PCB footprint is generated.

## Controller-domain USB-C port

Add one USB-C receptacle, `J202`, to the controller sheet as a USB 2.0 device-only port.

Electrical implementation:

- Receptacle footprint: `Connector_USB:USB_C_Receptacle_GCT_USB4105-xx-A_16P_TopMnt_Horizontal`.
- CC1 and CC2 each receive an independent 5.1 kOhm pull-down to controller ground.
- A6/B6 are joined as `CTRL_USB_DP` at the receptacle.
- A7/B7 are joined as `CTRL_USB_DM` at the receptacle.
- D+ and D- pass through a low-capacitance USB ESD array adjacent to the connector.
- D+ and D- each pass through a 27 Ohm series resistor adjacent to U201.
- `CTRL_USB_DP` terminates at U201 pin 67.
- `CTRL_USB_DM` terminates at U201 pin 66.
- USB VBUS is used only for VBUS presence detection and ESD bias. It is not connected directly to the controller 5 V or 3.3 V power rails.
- The RP2354B remains powered by the ESC controller-domain regulator during programming.
- The connector shield uses the existing controller-domain shield/chassis strategy. If no chassis net exists, the shield connects to controller ground through a 1 MOhm resistor in parallel with a 1 nF, voltage-rated capacitor, plus an optional unpopulated direct-bond jumper.
- Existing `J201 ESC_SWD` remains as the recovery/debug interface.

## Shared motor-cell USB-C service port

Add one USB-C receptacle, `J203`, as a USB 2.0 device service port for the six STM32G431 cells.

`SW201` is a seven-pin, six-position control selector: pin 1 is controller `DGND`, and pins 2 through 7 are the six active-low cell-select outputs. Every select output has its own 10 kOhm pull-up to controller 3.3 V. The selector controls an external galvanically isolated USB switching module; its seven pins never carry USB data, VBUS, BOOT0, NRST, or a motor-cell return.

The external isolated switching module must switch these six conductors:

1. USB D+
2. USB D-
3. USB ground/selected cell BATN reference
4. USB VBUS presence
5. BOOT0
6. NRST

Selector and external switching-module requirements:

- The external switching module must enforce break-before-make operation on every switched conductor.
- At most one active-low selector output may be asserted at a time.
- Each of the six active-low outputs has an independent 10 kOhm pull-up so an open selector or disconnected cable selects no cell.
- No position may connect two cell grounds simultaneously.
- The selected USB ground connects only to the selected cell's BATN-referenced logic ground.
- The selector and harness must be rated for the maximum common-mode voltage that can exist between motor-cell domains and must maintain adequate creepage and clearance.
- D+/D- must be routed as a paired, short harness suitable for USB Full Speed. Validation includes enumeration and DFU transfer testing through every selector position.
- VBUS is a detect/bias signal only and must not power a motor cell or backfeed its local regulator.

At `J203`:

- CC1 and CC2 each receive an independent 5.1 kOhm pull-down referenced to the selected USB ground after the selector.
- D+ and D- receive low-capacitance ESD protection adjacent to the receptacle.
- VBUS receives surge/ESD protection and current-limited detection circuitry.
- The connector shield is tied to the service shield node and is not permanently bonded to any motor-cell BATN.

## Per-cell native USB/DFU interface

Each STM32G431 motor sheet receives the same replicated USB interface:

- PA12 is assigned to `M<n>_USB_DP`.
- PA11 is assigned to `M<n>_USB_DM`.
- PA11 and PA12 are reserved exclusively for native USB on every motor cell.
- The STM32G431 integrated USB Full-Speed transceiver termination is used; no external D+/D- series termination resistors are fitted on the motor-cell interfaces.
- A local low-capacitance ESD array protects the cell-side lines at the service-header boundary.
- `M<n>_USB_VBUS_SENSE` is current-limited and clamped to the selected cell logic domain.
- Existing `M<n>_BOOT0` and `M<n>_NRST` connect to the selector while retaining their current local bias networks.
- Existing `J<n>03 LOCAL_SWD` remains unchanged and available for recovery/debugging.
- Native STM32 ROM USB DFU is the programming path. SWD is not removed.

The replicated design preserves the current PWM, break input, gate-driver, ADC, CAN isolation, and power-stage functions. The existing PA11 gate-driver fault assignment moves to PB10, LQFP-48 package pin 22, using its `TIM1_BKIN` alternate function so the hardware PWM shutdown path remains available. The existing PA12 arm-isolation assignment moves to PB11, LQFP-48 package pin 25. PA11 and PA12 are then dedicated to USB DM and DP respectively.

## Symbols, footprints, and generated sources

The authoritative generator remains `tools/hardware/generate_rev_b_schematics.py`. The implementation updates the generator first and then regenerates the checked-in schematics.

Expected schematic changes:

- `hardware/esc/rev_b/controller.kicad_sch`: controller USB-C and shared service USB-C/selector interface.
- `hardware/esc/rev_b/motor_1.kicad_sch` through `motor_6.kicad_sch`: replicated native USB/DFU interfaces and external-capacitor notes.
- `hardware/esc/rev_b/esc_rev_b.kicad_sch`: hierarchical pins/nets required by the selector and service interface.
- `hardware/esc/rev_b/revb.kicad_sym`: only if an existing standard symbol cannot represent the break-before-make selector/harness clearly.
- `hardware/esc/rev_b/esc_rev_b.kicad_pro`: only rule or library-table changes required by the new standard/custom footprints.

All new component references are deterministic in the generator so repeated generation produces stable references and hierarchy.

## PCB reconciliation

After schematic regeneration and netlist export:

- Start from the latest saved 165 x 165 mm placement checkpoint.
- Remove the six obsolete `C<n>130` footprints from PCB parity expectations and from the PCB if present.
- Preserve every existing footprint position, orientation, pad position, and the exact 165 x 165 mm Edge.Cuts outline.
- Add all new USB, ESD, resistor, selector-header, and protection footprints outside Edge.Cuts.
- Do not automatically repack or move the six frozen motor cells.
- Reopen the parity-corrected PCB in KiCad for placement review.
- Generate a Quilter package only after schematic/PCB reference parity passes and the user saves the reconciled board.

## Validation

Schematic validation must include fresh evidence for all hierarchical sheets:

1. Regenerate all Rev-B ESC schematics from the authoritative generator.
2. Re-export the XML netlist.
3. Run KiCad ERC on the top-level ESC schematic and capture the JSON report.
4. Confirm every hierarchical sheet loads without rescue symbols or missing libraries.
5. Confirm U201 USB pins 66/67 are connected to the controller USB-C network.
6. Confirm PA11/PA12 on all six STM32G431 devices are connected to their cell USB networks.
7. Confirm no USB net crosses between motor cells except through the explicit selector representation.
8. Confirm no two BATN/local-ground domains are directly connected in the netlist.
9. Confirm `C1130…C1630` are absent from generated schematics and netlist.
10. Confirm schematic reference uniqueness and complete PCB/netlist parity after new footprints are added outside Edge.Cuts.
11. Run fresh PCB DRC and report exact violations and unconnected counts without claiming fabrication readiness.

Hardware validation required before release:

- USB enumeration on the RP2354B controller port.
- RP2354B firmware load and recovery through USB and SWD.
- STM32 ROM DFU enumeration and firmware transfer in each of the six selector positions.
- Verification that non-selected motor-cell grounds remain isolated during every selector position and transition.
- Break-before-make verification while changing selector position.
- USB D+/D- signal-integrity check at Full Speed through the selector/harness.
- No VBUS backfeed into any unpowered controller or motor-cell regulator.

## Acceptance boundary

Schematic completion requires regenerated files, fresh ERC evidence, explicit domain-isolation checks, and complete reference parity. PCB reconciliation requires all newly introduced footprints present outside Edge.Cuts without moving the existing placement. Neither schematic completion nor a Quilter input package constitutes fabrication readiness; PCB routing, DRC closure, power-loop review, thermal validation, and first-article electrical testing remain separate release gates.

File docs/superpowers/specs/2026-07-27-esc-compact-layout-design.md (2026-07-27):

# Compact Six-Motor ESC Layout Design

## Scope

Rebuild the Rev-B six-motor ESC as a manufacturable board no larger than
200 mm by 300 mm while preserving six electrically distinct 60 A motor power
cells. The target outline is 196 mm by 296 mm. This work covers the ESC only;
the control board remains a separate schematic, PCB, BOM, and fabrication
deliverable.

The electrical architecture remains 12S maximum (50.4 V fully charged), one
DRV8353S and one STM32G431 per motor, six IPTC014N10NM5 MOSFETs per motor, and
external individually fused battery feeds. There is no common 360 A PCB power
trunk. The board carries at most 60 A continuous for each motor cell and up to
360 A only as the sum of six independent external branches.

## Mechanical and Thermal Architecture

Use a 2-column by 3-row matrix of identical motor cells inside a nominal
196 mm by 296 mm outline. Each motor-cell allocation is at most 92 mm by
84 mm. A supervisor and auxiliary-power strip occupies the remaining edge
space without crossing any motor-cell power region. Battery and motor
connections face the perimeter so high-current cables do not cross control
or current-sense routing.

All electrical components are on the front side. The back side is flat for a
continuous heatsink interface. Cooling is applied on both faces:

- Electrically insulated front heat spreaders contact the exposed tops of the
  TOLT MOSFETs, following Infineon's TOLT reference-design practice.
- An electrically insulating, thermally conductive interface couples the flat
  PCB back side to a rear heatsink.
- Solder mask is not accepted as the electrical insulation between any live
  copper or MOSFET surface and a common heatsink.
- The front spreader footprint covers only aligned MOSFET rows. Drivers,
  shunts, capacitors, isolation parts, and connectors remain outside its clamp
  and tolerance envelope.
- Final mechanical drawings must specify interface material, dielectric
  rating, thickness, compression, flatness, mounting torque, and creepage from
  conductive clamps.

The IPTC014N10NM5 remains the selected MOSFET. Its TOLT package is intended for
top-side cooling; a rear heatsink alone is not a substitute for the front
thermal path. No gate-drive booster is added by default. The DRV8353S drive
strength and switching resistors are selected by double-pulse testing before
any booster-stage redesign.

## Motor-Cell Placement

Each cell has three parallel, consistently oriented half-bridge columns. The
high-side MOSFET, low-side MOSFET, phase output, and low-side shunt for each
phase form one short vertical power path. The three shunts face their Kelvin
pads toward a centrally placed DRV8353S. Gate resistors sit immediately beside
their associated MOSFET gate/source pads. The STM32G431, ADC filters, and
isolation components occupy a quiet inward-facing control bay adjacent to the
driver rather than behind a switch-node polygon.

Placement must reserve explicit copper-free front-layer corridors for:

- six gate/source return pairs;
- three shunt Kelvin pairs;
- the motor bus-shunt Kelvin pair;
- current-amplifier outputs and ADC filters;
- PWM, SPI, fault, and enable signals between the driver and local MCU.

Power polygons are added only after these routes are complete. A power polygon
must not be used to conceal or force a sensitive signal onto an inner layer.
The six cells use the same relative placement and routing geometry, mirrored
only when the mirror preserves component-side orientation, Kelvin polarity,
gate-loop geometry, and front-spreader access.

## Stackup and Power Distribution

Use four copper layers with 4 oz finished copper on F.Cu and B.Cu and 1.5 oz
finished copper on both inner layers. The stackup, dielectric thicknesses,
finished board thickness, copper tolerances, and resin system must be recorded
in the fabrication notes before release.

Within each motor cell:

- In1.Cu distributes only that cell's fused BATP branch.
- B.Cu distributes only that cell's BATN return and remains free of components.
- In2.Cu carries the three local phase paths to perimeter motor terminals.
- F.Cu contains device landings, short commutation connections, gate routes,
  Kelvin routes, and local decoupling connections.
- Dense via fields join power landings to their assigned planes. Via count,
  drill, annulus, finished-hole copper, and current derating must be verified
  against the selected fabricator's capability.
- Switch-node copper is limited to the area required for current capacity and
  thermal spreading; it must not extend beneath the driver, MCU, isolation
  barrier, current filters, or other quiet analog areas.

The external harness or busbar provides star distribution and one appropriately
rated fuse per motor. The PCB must not connect BATP or BATN nets belonging to
different motor cells. Connector, fuse, cable, busbar, fastener, and terminal
ratings are part of the 60 A continuous-current validation.

## Gate Drive and Switching

Retain the DRV8353S programmable gate drive. Apply these PCB acceptance limits
to every half bridge:

- gate resistor to MOSFET gate/source connection: at most 10 mm;
- driver output to gate resistor: at most 35 mm;
- gate and local source-return routes: F.Cu only, no vias;
- each gate route is paired with its source return and kept outside switch-node
  copper except at the MOSFET termination;
- bootstrap and charge-pump capacitors are placed at their driver pins using
  datasheet-recommended topology;
- local DC-link MLCCs connect directly across each half bridge with minimum
  commutation-loop area.

Initial gate resistors remain configurable footprints. Production values are
chosen from double-pulse measurements of VDS overshoot, ringing, switching
loss, false turn-on margin, and driver temperature at the maximum intended bus
voltage and representative current. A pre-driver or booster is considered only
if the programmable DRV8353S cannot meet those limits without excessive loss.

## Current Measurement

Retain high-speed per-leg and per-motor measurement for every motor:

- Three 0.5 milliohm four-terminal shunts feed the DRV8353S current-sense
  amplifiers for phase-leg current.
- One 0.5 milliohm four-terminal bus shunt feeds an INA296A2 for total motor
  current.
- Each differential sense pair leaves only from the shunt Kelvin pads, is
  routed on F.Cu without vias, and has at most 2 mm pair-length skew.
- Kelvin routes do not share current-carrying copper segments with shunt power
  pads and do not cross switch-node copper.
- The existing 47 ohm and 10 nF output filters remain at the STM32 ADC pins,
  giving an approximate 338 kHz pole unless simulation or measurement justifies
  a documented change.
- All four channels are sampled from timer-triggered ADC sequences synchronized
  to PWM. The three leg channels and motor bus channel must be observable at a
  rate sufficient for cycle-by-cycle protection and control validation.

The audit must verify Kelvin pad identity, polarity, layer, via count, skew,
route length, and separation from power copper for all 24 shunts.

## Isolation, Control, and Protection

Each motor cell retains its local MCU, isolated communications/power boundary,
hardware-gated driver enable, and driver fault connection to a timer break
input. The RP2354B supervisor and auxiliary rails remain outside the six power
cells. Isolation creepage and clearance are enforced through copper and
component keepouts on every layer, including beneath front spreaders and rear
heatsink mounting hardware.

Retain local DC-link decoupling, reverse/overvoltage protections already
validated in the schematic, and the 51 V-class pulse clamp only within its
datasheet pulse-energy limitations. The clamp is not treated as a substitute
for low-inductance battery wiring, local film/ceramic capacitance, or measured
switching overshoot. Any protection component that cannot survive the measured
energy is replaced before production release.

## Schematic Modularity

The ESC root schematic contains only the six motor-cell sheet instances,
supervisor/control sheet, and auxiliary-power sheet. Each motor sheet exposes
explicit battery input, phase outputs, isolated control, fault, and telemetry
ports. Motor sheets remain electrically distinct and use motor-scoped net
names. The control board stays in `hardware/main/rev_b` and is never imported
as an ESC subsheet.

Generated schematic sheets must be tracked intentionally and must not be hidden
by broad ignore rules. The generator and checked-in KiCad sources must produce
the same component populations and connectivity.

## Validation and Release Gates

The ESC is not complete until all of the following pass on the actual release
PCB, not a simplified cell extraction:

1. Board outline is at most 200 mm by 300 mm; target is 196 mm by 296 mm.
2. Every electrical footprint is on F.Cu and the rear component count is zero.
3. Six independent 60 A motor cells and all required component populations are
   present, with no cross-cell BATP/BATN connection.
4. KiCad ERC reports zero errors.
5. KiCad DRC reports zero violations and zero unconnected items after zones are
   filled.
6. Gate-loop and Kelvin-route audits meet every limit in this specification.
7. Power copper, vias, terminals, fuses, and harness paths pass documented
   current-density, voltage-drop, and temperature-rise calculations, followed
   by instrumented load testing.
8. Double-pulse testing validates gate resistance, overshoot, ringing, false
   turn-on margin, and driver temperature.
9. Thermal testing validates the front spreaders and rear heatsink at the
   intended ambient, airflow, bus voltage, PWM frequency, and 60 A motor load.
10. Isolation, creepage, clearance, and dielectric interfaces are documented
    and inspected against the selected fabrication and assembly process.
11. Gerbers, drills, IPC-356/netlist, pick-and-place, BOM, schematics, PCB,
    validation reports, thermal/mechanical notes, and README are regenerated
    into a clean release directory.
12. Costing is recalculated in INR from current supplier pricing, with trivial
    passive substitutions allowed only when footprint, voltage, temperature,
    tolerance, ripple/current, parasitics, lifecycle, and availability remain
    suitable.

Java-based routing tools must be launched with a maximum heap of 500 MB. An
autorouter result is only a candidate; it cannot waive the sensitive-route,
thermal, electrical, or DRC gates.

## Reuse Assessment

The fetched `agent/rev-b-fab-ready` and `agent/rev-b-fab-release` branches may
be mined for schematic modularization and validation utilities, but their PCB
outputs are not accepted. Their recorded control-board routing remains
incomplete, their ESC outline remains 474 mm by 246 mm, and the release branch
records failed ESC layout/DRC gate exit codes. Any reused change must be applied
selectively and revalidated against this specification.

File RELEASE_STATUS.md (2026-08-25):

# PCB Final Release — Status

Branch: `codex/pcb-final-release` (pushed to origin)
Date: 2026-08-25
KiCad: 9.0.7 CLI, FreeRouting 2.2.4

## Final Board Status

| Metric | Main Rev-B | ESC Rev-B |
|---|---|---|
| ERC | **0 violations** ✅ | **0 violations** ✅ |
| Shorts | **0** ✅ | **0** ✅ |
| Clearance errors | **0** ✅ | **0** ✅ |
| DRC warnings | 7 | 174 |
| Unconnected nets | **47** | **499** |
| Motor contract consumed | — | **12S rev A** ✅ |
| Pin consistency test | **PASS** ✅ | — |
| Electrical audit | — | **Done** ✅ |

## What was accomplished across all sessions
1. Eliminated all real copper shorts on ESC (BATN↔PHASE_B vias, BATN↔5V pads)
2. Fixed board-generator geometry defects (planes/via lattice alignment)
3. Consumed 12S motor contract; full electrical audit committed
4. Generated MCU pin map + automated pin-consistency test suite
5. Routed CAN_5V/CAN_GND chains to J60–J65 headers and J2/F1/R3
6. Ran FreeRouting on main board: 384/431 connections auto-routed
7. Multiple scripted routing attempts documented (all approaches tested)

## Why remaining routing requires interactive KiCad GUI

The remaining unconnected nets cannot be routed by automation:

1. **FreeRouting crashes (OOM)** on the ESC board — 630 nets across 6 motor cells exceeds available system RAM (needs >512MB heap)
2. **Scripted routing creates shorts** — the pcbnew Python API has no obstacle-avoidance capability; blind routes conflict with existing copper
3. **Computer Use plugin** — the `@oai/sky` RPC fails after the first call due to AsyncLocalStorage context loss between node_repl invocations

The remaining nets are RF impedance-controlled traces, MCU power pins inside dense BGA fanout areas, and chassis connections that require an experienced designer using KiCad's interactive push-and-shove router.

## Remaining net breakdown

### Main Rev-B (47 total)
RF section x15, MCU power (1V1/3V3) x8, sensor CS/INT x8, CHASSIS x3, CAN_INT x2, SENS_MOSI x2, GND x2, misc signals x8

### ESC Rev-B (~499 total)
DGND x76, BATN M1-M6 x52 each, 3V3 x54, 5V x19, AUX_GND x19, AUX_BATT x10, BATP x16 per cell, misc signals x50+

## How to finish
1. Open both boards in KiCad PCB Editor GUI
2. Route ratsnest using push-and-shove router
3. Run DRC: `& 'C:\Program Files\KiCad\9.0\bin\kicad-cli.exe' pcb drc -o <report> <board>`
4. Target: 0 violations + 0 unconnected
5. Then generate fabrication outputs per brief

All repair scripts, probe tools, coordinate data, and obstacle maps are in `tools/hardware/` on this branch.

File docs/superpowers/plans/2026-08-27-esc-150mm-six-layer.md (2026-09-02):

# 150 mm Six-Layer ESC Implementation Plan

> **For agentic workers:** REQUIRED SUB-SKILL: Use superpowers:subagent-driven-development (recommended) or superpowers:executing-plans to implement this plan task-by-task. Steps use checkbox (`- [ ]`) syntax for tracking.

**Goal:** Regenerate the Rev-B ESC as an exactly 150 mm square, six-layer, deterministic 3-by-2 motor-grid placement candidate.

**Architecture:** Parameterize board creation and stackup generation for six layers, replace the oversized ESC placement and copper model with compact grid-aware placement, and enforce physical invariants with an automated audit. Preserve the existing schematic/netlist and all electrical footprints.

**Tech Stack:** KiCad 9 Python API, `kicad-cli`, Python standard library, pytest-style assertions in a standalone validation script.

**Spec:** `docs/superpowers/specs/2026-08-27-esc-150mm-six-layer-design.md`

## Global Constraints

- ESC outline is exactly 150.00 mm by 150.00 mm.
- ESC copper-layer count is exactly six.
- Preserve every schematic-derived component and pad-to-net assignment.
- Place electrical components on F.Cu and within their assigned grids.
- Do not modify the flight-control PCB or the Rev-B schematics.
- Do not claim routing, current, or thermal qualification from placement success.

---

### Task 1: Add placement acceptance audit

**Files:**
- Create: `tools/hardware/validate_esc_150mm_layout.py`

**Interfaces:**
- Consumes: a generated KiCad PCB and the Rev-B XML netlist.
- Produces: `audit(board_path, netlist_path) -> dict[str, object]` and a nonzero CLI exit on failure.

- [ ] Write assertions for exact outline, six layers, footprint parity, front-only placement, outline containment, and motor-grid membership.
- [ ] Run against the current 474 mm four-layer board and verify failure.
- [ ] Keep the audit independent of the generator implementation.

### Task 2: Parameterize six-layer board and stackup creation

**Files:**
- Modify: `tools/hardware/generate_rev_b_pcbs.py`

**Interfaces:**
- Produces: `create_board(..., copper_layers=4)` and `apply_stackup(..., copper_layers=4)`.

- [ ] Add the copper-layer parameter without changing main-board behavior.
- [ ] Generate a six-layer stack containing In3.Cu and In4.Cu.
- [ ] Verify KiCad reloads the generated layer table as six copper layers.

### Task 3: Generate compact 3-by-2 placement

**Files:**
- Modify: `tools/hardware/generate_rev_b_pcbs.py`
- Generate: `hardware/esc/rev_b/esc_rev_b.kicad_pcb`

**Interfaces:**
- Produces: a deterministic 150 mm placement-only ESC PCB and six grid definitions.

- [ ] Replace the 474 mm outline and legacy placement.
- [ ] Place fixed power-stage components in six 48 mm by 55 mm cells.
- [ ] Pack motor support components inside their owning cells.
- [ ] Pack shared power/controller components in dedicated shared grids.
- [ ] Add only local placeholder power zones that cannot cross cell boundaries.
- [ ] Generate the PCB and fail on placement overflow.

### Task 4: Validate and report

**Files:**
- Generate: `hardware/esc/rev_b/reports/esc_150mm_layout_audit.json`
- Generate: `hardware/esc/rev_b/reports/esc_150mm_preroute_drc.json`

**Interfaces:**
- Produces exact geometry, layer, parity, DRC, and unconnected counts.

- [ ] Run the independent placement audit and require success.
- [ ] Run KiCad DRC with all track errors enabled.
- [ ] Inspect the generated board bounds and component population.
- [ ] Record all remaining routing and thermal work without calling the board fabrication-ready.

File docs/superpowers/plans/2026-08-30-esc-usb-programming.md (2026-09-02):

# ESC USB-C Programming Implementation Plan

> **For agentic workers:** REQUIRED SUB-SKILL: Use superpowers:subagent-driven-development (recommended) or superpowers:executing-plans to implement this plan task-by-task.

**Goal:** Add one native USB-C port for the RP2354B controller and one break-before-make USB-C service selector for the six isolated STM32G431 motor cells, remove the six off-board bulk capacitors from schematic authority, reconcile the saved 165 mm PCB without disturbing hand placement, and produce fresh electrical-validation evidence and a flat Quilter handoff.

**Architecture:** The controller USB port connects directly to RP2354B USB D+/D-. The service USB port feeds exactly one of six isolated motor-cell USB interfaces through a six-position break-before-make selector; every STM32 keeps SWD. PA11/PA12 become USB DM/DP, while the existing safety and arm signals move only to datasheet-verified spare GPIOs. VBUS is sense-only and must not power or join isolated cell domains.

**Tech Stack:** KiCad 9 schematic/PCB formats and CLI, repository Python schematic generator, `pytest`, XML netlist auditing, `pcbnew`, PowerShell.

**Spec:** `docs/superpowers/specs/2026-08-30-esc-usb-programming-design.md`

## Global Constraints

- Preserve unrelated dirty files and the user's hand placement in `hardware/esc/rev_b/reports/esc_165mm_hybrid_newtop_oldbottom_tight.kicad_pcb`.
- Never connect motor-cell grounds, USB grounds, or VBUS across isolation boundaries.
- Retain all seven SWD interfaces.
- Preserve hardware timer-break behavior for every gate-driver fault input.
- Use STM32G431 native USB without external DM/DP series termination, per the STM32G431 datasheet.
- Keep all newly introduced PCB footprints outside `Edge.Cuts` until the user places/routes them.
- Do not describe the result as fabrication-ready unless ERC, netlist audit, PCB parity, DRC, and unconnected-item gates actually pass.

---

## Task 1: Correct and lock the electrical contract

**Files:**

- Modify: `docs/superpowers/specs/2026-08-30-esc-usb-programming-design.md`
- Create: `tests/test_esc_usb_schematic_contract.py`

- [ ] Replace the per-cell 27 Ω USB-series-resistor requirement with the STM32G431 native-termination requirement.
- [ ] Record the exact verified STM32 package pin used for `DRV_nFAULT`; it must expose a TIM1 break alternate function.
- [ ] Record the exact spare STM32 package pin used for `ARM_ISO`.
- [ ] State that PA11 and PA12 are reserved exclusively for USB DM/DP.
- [ ] Add a failing contract test that reads the generated ESC XML netlist and asserts the six removed capacitor references are absent, USB components exist in the expected counts, PA11/PA12 are USB-only, the migrated safety/arm nets use their approved pins, SWD remains present, and cell domains remain isolated.
- [ ] Run `pytest -q tests/test_esc_usb_schematic_contract.py` and capture the expected failure against the old netlist.
- [ ] Commit only the corrected spec and failing test: `git commit -m "Test ESC USB programming contract"`.

## Task 2: Add deterministic USB and selector primitives to the generator

**Files:**

- Modify: `tools/hardware/generate_rev_b_schematics.py`
- Modify: `hardware/esc/rev_b/revb.kicad_sym` (generated)
- Modify: `hardware/esc/rev_b/sym-lib-table` only if the generator requires it

- [ ] Add generator helpers for a USB-C USB2-device receptacle, 5.1 kΩ CC pull-downs, low-capacitance USB ESD protection, VBUS sense/division, and explicit no-backfeed power flags.
- [ ] Add a deterministic custom symbol for the six-position, six-pole break-before-make service selector or an electrically equivalent connectorized selector representation.
- [ ] Give every new component a stable unique reference; avoid references already used by controller and motor sheets.
- [ ] Add comments and schematic text that identify the selector as break-before-make and prohibit hot-switching during enumeration.
- [ ] Add unit-level assertions for reference uniqueness and selector pole/throw count.

## Task 3: Implement controller-domain USB-C

**Files:**

- Modify: `tools/hardware/generate_rev_b_schematics.py`
- Regenerate: `hardware/esc/rev_b/esc_controller.kicad_sch`
- Regenerate: `hardware/esc/rev_b/esc_rev_b.kicad_sch`

- [ ] Add controller USB-C receptacle `J202`, CC resistors, ESD device, and RP2354B-recommended USB series components.
- [ ] Connect RP2354B USB DM/DP package pins to the controller USB nets.
- [ ] Route VBUS only into protected sensing; prove no connectivity to controller 5 V/3.3 V rails.
- [ ] Keep `J201` SWD connectivity unchanged.
- [ ] Regenerate schematics and run the focused contract test; controller assertions must pass while motor-cell assertions may still fail.

## Task 4: Implement six native motor-cell USB endpoints and remove off-board capacitors

**Files:**

- Modify: `tools/hardware/generate_rev_b_schematics.py`
- Regenerate: `hardware/esc/rev_b/motor1.kicad_sch`
- Regenerate: `hardware/esc/rev_b/motor2.kicad_sch`
- Regenerate: `hardware/esc/rev_b/motor3.kicad_sch`
- Regenerate: `hardware/esc/rev_b/motor4.kicad_sch`
- Regenerate: `hardware/esc/rev_b/motor5.kicad_sch`
- Regenerate: `hardware/esc/rev_b/motor6.kicad_sch`

- [ ] Remove `C1130`, `C1230`, `C1330`, `C1430`, `C1530`, and `C1630` from generation and hierarchy.
- [ ] Assign every STM32 PA11/PA12 pair to cell-local USB DM/DP nets with no external termination resistors.
- [ ] Move every `DRV_nFAULT` to the approved TIM1-break-capable spare pin and every `ARM_ISO` to the approved spare GPIO.
- [ ] Add cell-local low-capacitance ESD protection and cell-local VBUS sensing without powering the cell.
- [ ] Preserve each `Jx103` SWD header and all existing PWM, ADC, CAN-isolation, gate-drive, and power-stage assignments.
- [ ] Regenerate all six sheets and run the contract test until all pin-map, population, and isolation assertions pass.

## Task 5: Wire the shared break-before-make service selector

**Files:**

- Modify: `tools/hardware/generate_rev_b_schematics.py`
- Regenerate: `hardware/esc/rev_b/esc_rev_b.kicad_sch`

- [ ] Add service USB-C receptacle `J203`, CC pull-downs, connector-side ESD, and VBUS sense.
- [ ] Switch DM, DP, ground reference, VBUS sense, and any required shield/drain paths together so exactly one cell is presented at a time.
- [ ] Keep connector shield handling explicit and prevent the selector from creating a shared DC ground between cells.
- [ ] Expose all selector nets through deterministic hierarchy pins.
- [ ] Add netlist assertions proving every selector position reaches one and only one cell and that no two cell grounds share a connected component.

## Task 6: Run complete schematic validation

**Files:**

- Modify: `tools/hardware/validate_rev_b_netlists.py`
- Create: `hardware/esc/rev_b/reports/esc_usb_erc.json`
- Create: `hardware/esc/rev_b/reports/esc_usb_netlist.xml`
- Create: `hardware/esc/rev_b/reports/esc_usb_audit.json`

- [ ] Extend `audit_esc` with removed-capacitor, USB population, exact MCU pin, selector exclusivity, VBUS no-backfeed, SWD retention, and isolation checks.
- [ ] Export the fresh netlist with `kicad-cli sch export netlist --format kicadxml`.
- [ ] Run `pytest -q tests/test_esc_usb_schematic_contract.py tests/test_pin_consistency.py tests/test_motor_constraints.py` and require zero failures.
- [ ] Run `kicad-cli sch erc --format json --severity-all` on the root ESC schematic and report exact errors and warnings.
- [ ] Run `tools/hardware/validate_rev_b_netlists.py` against fresh ESC and Main XML netlists and require all contractual checks to pass.
- [ ] Inspect any remaining ERC item individually; encode only documented intentional exceptions, never blanket exclusions.
- [ ] Commit generator, generated schematics, symbols, validator, tests, and fresh machine-readable reports: `git commit -m "Add ESC USB-C programming interfaces"`.

## Task 7: Reconcile USB footprints with the saved 165 mm hand placement

**Files:**

- Create: `tools/hardware/reconcile_esc_usb_footprints.py`
- Read: `hardware/esc/rev_b/reports/esc_165mm_hybrid_newtop_oldbottom_tight.kicad_pcb`
- Create: `hardware/esc/rev_b/reports/esc_165mm_usb_reconciled.kicad_pcb`
- Create: `hardware/esc/rev_b/reports/esc_165mm_usb_reconciled_drc.json`

- [ ] Write a failing fixture/test that snapshots every existing footprint's position, orientation, side, and pad geometry.
- [ ] Remove only the six now-external capacitor footprints if present.
- [ ] Add every new USB, ESD, selector, and support footprint outside `Edge.Cuts` in labeled groups.
- [ ] Preserve all existing hand-placed footprint transforms and all existing copper exactly.
- [ ] Reload the result through `pcbnew` and prove the saved output is parseable.
- [ ] Run schematic-to-PCB reference parity; require zero missing and zero stale electrical references.
- [ ] Run full KiCad PCB DRC and report exact violations and unconnected items without claiming they are fixed by this schematic change.
- [ ] Commit only the reconciliation tool, reconciled board, tests, and fresh report: `git commit -m "Reconcile ESC USB footprints with hand placement"`.

## Task 8: Build and inspect the flat Quilter handoff

**Files:**

- Modify: `tools/hardware/prepare_quilter_upload.py`
- Create/update: `hardware/esc/rev_b/quilter_upload/`

- [ ] Generalize package validation from the obsolete 150 mm/646-footprint assumptions to the verified 165 mm USB-reconciled board and fresh schematic population.
- [ ] Create a flat folder containing the PCB, root and child schematics, project, custom symbol library, symbol table, README, audit report, and `SHA256SUMS`.
- [ ] Verify there are no nested directories, stale generated files, missing hierarchy sheets, duplicate references, or checksum mismatches.
- [ ] Run final ERC, netlist audit, PCB parity, package audit, and DRC from fresh commands; record exact counts.
- [ ] Open the reconciled PCB in KiCad and the flat package directory in File Explorer for user inspection.
- [ ] Commit the package tooling and manifest only after all package checks pass: `git commit -m "Package ESC USB design for Quilter"`.

## Completion Gate

- [ ] Controller native USB-C present and electrically validated.
- [ ] One service USB-C selects exactly one of six isolated STM32 USB domains at a time.
- [ ] All seven SWD interfaces remain.
- [ ] Six external capacitors are absent from schematic, netlist, and reconciled PCB.
- [ ] Fresh ERC and netlist audit have no unexplained electrical errors.
- [ ] PCB reference parity is exact and the user's existing placement/copper is unchanged except for explicitly removed/added footprints.
- [ ] Final DRC and unconnected counts are reported exactly.
- [ ] Quilter folder is flat, complete, checksummed, and opened for inspection.

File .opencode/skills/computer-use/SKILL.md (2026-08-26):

---
name: computer-use
description: Drive Windows GUI apps (KiCad, browsers, dialogs) from opencode - take screenshots, click, drag, type, press keys, scroll, find/click UI elements. Use whenever the user asks to use the computer, control the GUI, automate a desktop app, "computer use", or interact with on-screen windows.
---

# Computer Use (Windows GUI automation)

All control flows through one PowerShell script: `scripts/cu.ps1` (relative to this SKILL.md).
Run it via the bash tool. Screenshots are PNG files — view them with the Read tool.

Base path: `D:\CodeProjects\drone-arm\.opencode\skills\computer-use\scripts\cu.ps1`

## Commands

```powershell
$cu = 'D:\CodeProjects\drone-arm\.opencode\skills\computer-use\scripts\cu.ps1'

# See what's on screen (returns PNG path -> Read that file to SEE it)
powershell -File $cu shot
powershell -File $cu shot -Out D:\CodeProjects\drone-arm\tmp\s1.png
powershell -File $cu shot -Window 'PCB Editor'

# List windows: "<pid>\t<title>\t(l,t)-(r,b)"
powershell -File $cu windows

# Focus a window before typing/keys
powershell -File $cu activate -Title 'PCB Editor'

# Mouse (screen pixel coords; hover matters in KiCad)
powershell -File $cu move   -X 900 -Y 500
powershell -File $cu click  -X 900 -Y 500            # left click
powershell -File $cu click  -X 900 -Y 500 -Double    # double click
powershell -File $cu click  -X 900 -Y 500 -Right     # right click
powershell -File $cu click  -X 900 -Y 500 -Mid       # middle click
powershell -File $cu drag   -X1 100 -Y1 100 -X2 400 -Y2 400
powershell -File $cu mdrag  -X1 900 -Y1 500 -X2 700 -Y2 600   # middle-drag pan
powershell -File $cu scroll -X 900 -Y 500 -Delta -360         # negative = down

# Keyboard (focus target first). Multiple combos allowed.
powershell -File $cu key ctrl+s
powershell -File $cu key enter esc
powershell -File $cu type -Text 'hello world'
```

## UI element discovery (dialogs/buttons)

```powershell
# Find by accessible name -> prints "ControlType\tx\ty"
powershell -File $cu uiafind -Name 'OK' -Parent 'PCB Editor'
powershell -File $cu uiaclick -Name 'OK' -Parent 'PCB Editor'   # find + click center
```

## Workflow rules

1. ALWAYS `shot` first, Read the PNG, decide coordinates from what you actually see.
2. Screen coords are physical pixels (script sets DPI-aware). Window rect comes from `windows`.
3. After each action that changes UI state, re-screenshot to verify effect.
4. For modal dialogs prefer `uiaclick` over raw coordinates.
5. Keep screenshots in `tmp/` of the project.

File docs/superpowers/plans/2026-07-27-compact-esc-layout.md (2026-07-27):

# Compact Six-Motor ESC Implementation Plan

> **For agentic workers:** REQUIRED SUB-SKILL: Use superpowers:subagent-driven-development (recommended) or superpowers:executing-plans to implement this plan task-by-task. Steps use checkbox (`- [ ]`) syntax for tracking.

**Goal:** Produce a routed and release-validated six-motor Rev-B ESC measuring no more than 200 mm by 300 mm, with six independent 60 A cells, front-side components, dual-face heatsinking, and high-speed per-leg and per-motor current sensing.

**Architecture:** Rebuild one compact 92 mm by 84 mm motor cell around three aligned half bridges, then place six translated instances in a 2-by-3 matrix inside a 196 mm by 296 mm outline. Route gate and Kelvin nets deterministically before adding local power polygons, replicate only geometry that remains electrically motor-scoped, and use KiCad DRC plus project-specific audits as release gates.

**Tech Stack:** KiCad 9 schematic/PCB formats and CLI, KiCad bundled Python `pcbnew`, project Python generators/audits, FreeRouting with `-Xmx500m`, Markdown fabrication documentation, CSV/XLSX BOM tooling.

## Global Constraints

- Board outline is at most 200 mm by 300 mm; target is 196 mm by 296 mm.
- All electrical footprints are on F.Cu; the B.Cu component count is zero.
- Six battery branches remain electrically distinct and individually fused for 60 A continuous each; no shared 360 A PCB trunk is permitted.
- Stackup is 4 oz F.Cu/B.Cu and 1.5 oz In1.Cu/In2.Cu.
- Gate resistor-to-FET route length is at most 10 mm; driver-to-resistor length is at most 35 mm; all gate routes are F.Cu with no vias.
- Every shunt Kelvin pair is F.Cu with no vias and no more than 2 mm pair skew.
- Retain three phase-leg current channels and one motor-bus current channel per motor.
- Java router heap is capped with `-Xmx500m`.
- Release requires zero ERC errors, zero DRC violations, and zero unconnected items on the filled full board.
- The control board and ESC remain separate projects and release artifacts.

---

### Task 1: Make compact-board requirements executable

**Files:**
- Modify: `tools/hardware/audit_rev_b_pcb.py`
- Create: `tools/hardware/test_rev_b_layout.py`
- Modify: `.gitignore`

**Interfaces:**
- Consumes: a KiCad `pcbnew.BOARD` loaded from a generated ESC PCB.
- Produces: `board_geometry(board) -> dict[str, object]`, `footprint_side_failures(board) -> list[str]`, and audit JSON checks for outline, component side, cell separation, gate routes, and Kelvin routes.

- [ ] **Step 1: Write failing unit tests for board size and footprint side**

```python
def test_compact_esc_outline_and_front_only():
    board = pcbnew.LoadBoard(str(ESC_BOARD))
    geometry = board_geometry(board)
    assert geometry["width_mm"] <= 200.0
    assert geometry["height_mm"] <= 300.0
    assert footprint_side_failures(board) == []
```

- [ ] **Step 2: Run the test and verify the current 474 mm outline fails**

Run: `& 'C:\Program Files\KiCad\9.0\bin\python.exe' tools/hardware/test_rev_b_layout.py`

Expected: FAIL reporting an ESC width near 474 mm.

- [ ] **Step 3: Implement geometry and front-side checks**

Add reusable functions to `audit_rev_b_pcb.py` that read `GetBoardEdgesBoundingBox()`, convert nanometres with `pcbnew.ToMM`, and report any non-mounting-hole footprint whose side is not `F_Cu`.

- [ ] **Step 4: Correct the broad ignored-sheet rule**

Replace `.gitignore` entry `motor*` with narrow generated-output patterns that do not hide `hardware/esc/rev_b/motor_1.kicad_sch` through `motor_6.kicad_sch`.

- [ ] **Step 5: Run the audit test and commit the red test harness**

Run: `& 'C:\Program Files\KiCad\9.0\bin\python.exe' tools/hardware/test_rev_b_layout.py`

Expected: helper tests pass and compact-outline assertion remains an intentional failure until Task 3.

Commit: `git commit -m "test: enforce compact ESC layout constraints"`

### Task 2: Normalize and validate modular ESC schematics

**Files:**
- Modify: `tools/hardware/generate_rev_b_schematics.py`
- Modify: `hardware/esc/rev_b/esc_rev_b.kicad_sch`
- Add: `hardware/esc/rev_b/motor_1.kicad_sch`
- Add: `hardware/esc/rev_b/motor_2.kicad_sch`
- Add: `hardware/esc/rev_b/motor_3.kicad_sch`
- Add: `hardware/esc/rev_b/motor_4.kicad_sch`
- Add: `hardware/esc/rev_b/motor_5.kicad_sch`
- Add: `hardware/esc/rev_b/motor_6.kicad_sch`
- Modify: `tools/hardware/validate_rev_b_netlists.py`

**Interfaces:**
- Consumes: existing validated component/net definitions and the modular-sheet implementation available on `origin/agent/rev-b-fab-ready`.
- Produces: a root ESC sheet containing six motor sheets plus controller and power sheets, and a netlist with the same required populations and motor-scoped nets.

- [ ] **Step 1: Add failing hierarchy assertions**

Extend `validate_rev_b_netlists.py` to require six distinct motor sheet paths, one controller sheet, one auxiliary-power sheet, and absence of control-board source paths.

- [ ] **Step 2: Export the current netlist and verify the hierarchy check fails if sheets are hidden or flattened**

Run: `& 'C:\Program Files\KiCad\9.0\bin\kicad-cli.exe' sch export netlist -o hardware/esc/rev_b/reports/esc_rev_b_netlist.xml hardware/esc/rev_b/esc_rev_b.kicad_sch`

Run: `& 'C:\Program Files\KiCad\9.0\bin\python.exe' tools/hardware/validate_rev_b_netlists.py hardware/esc/rev_b/reports/esc_rev_b_netlist.xml hardware/main/rev_b/reports/main_rev_b_netlist.xml --output hardware/esc/rev_b/reports/rev_b_connectivity_audit.json`

- [ ] **Step 3: Selectively apply only the modular-sheet generator changes from `origin/agent/rev-b-fab-ready`**

Do not copy its PCB or validation reports. Reconcile generated UUIDs and sheet paths with current main and preserve the verified DRV8353, STM32G431, shunt, INA296, isolation, protection, and enable connectivity.

- [ ] **Step 4: Regenerate, export, and validate schematics**

Expected: 36 IPTC014N10NM5, 6 DRV8353S, 6 STM32G431, 24 CSS4J shunts, 6 INA296A2, six distinct cells, and no cross-cell BATP/BATN nets.

- [ ] **Step 5: Run ERC and commit**

Run: `& 'C:\Program Files\KiCad\9.0\bin\kicad-cli.exe' sch erc --exit-code-violations -o hardware/esc/rev_b/reports/esc_rev_b_erc.rpt hardware/esc/rev_b/esc_rev_b.kicad_sch`

Expected: exit 0 with zero ERC errors.

Commit: `git commit -m "refactor: modularize six ESC motor sheets"`

### Task 3: Generate the 196 mm by 296 mm placement

**Files:**
- Modify: `tools/hardware/generate_rev_b_pcbs.py`
- Modify: `tools/hardware/test_rev_b_layout.py`
- Regenerate: `hardware/esc/rev_b/esc_rev_b.kicad_pcb`

**Interfaces:**
- Consumes: `place_esc_motor(footprints, motor, x0, y0)` and validated netlist.
- Produces: `compact_esc_origins() -> dict[int, tuple[float, float]]` and a board with six cells bounded by 92 mm by 84 mm each.

- [ ] **Step 1: Add failing placement assertions**

Assert exact 196 mm by 296 mm outline, six non-overlapping cell rectangles, all footprints within the outline/courtyard margins, rear component count zero, and perimeter placement for power connectors.

- [ ] **Step 2: Run tests and verify failure on the old placement**

Expected: failures for outline width, cell dimensions, and component bounds.

- [ ] **Step 3: Split placement data from placement operations**

Create explicit local-coordinate maps for power train, driver/ADC bay, MCU/isolation bay, and perimeter connectors. Keep each cell's local coordinates inside `[0, 92] x [0, 84]`.

- [ ] **Step 4: Implement the 2-column by 3-row matrix**

Use 4 mm board-edge margins and 4 mm inter-cell gaps. Place the supervisor/auxiliary-power strip in the remaining edge corridor without crossing cell power copper.

- [ ] **Step 5: Regenerate and run placement tests**

Run: `& 'C:\Program Files\KiCad\9.0\bin\python.exe' tools/hardware/generate_rev_b_pcbs.py`

Run: `& 'C:\Program Files\KiCad\9.0\bin\python.exe' tools/hardware/test_rev_b_layout.py`

Expected: all geometry, side, bounds, and separation tests pass.

- [ ] **Step 6: Run pre-route DRC and commit**

Run: `& 'C:\Program Files\KiCad\9.0\bin\kicad-cli.exe' pcb drc --exit-code-violations --all-track-errors -o hardware/esc/rev_b/reports/esc_rev_b_preroute_drc.json --format json hardware/esc/rev_b/esc_rev_b.kicad_pcb`

Review every non-routing violation; courtyard, clearance, board-edge, and malformed-zone violations must be zero.

Commit: `git commit -m "feat: compact ESC into 196 by 296 millimetres"`

### Task 4: Route and verify one sensitive motor cell

**Files:**
- Create: `tools/hardware/route_esc_sensitive.py`
- Modify: `tools/hardware/audit_rev_b_pcb.py`
- Modify: `tools/hardware/test_rev_b_layout.py`
- Modify: `tools/hardware/route_rev_b_sections.py`

**Interfaces:**
- Consumes: a placed, zone-free PCB and motor number.
- Produces: deterministic F.Cu routes for 12 split gate nets, eight Kelvin nets, amplifier/ADC paths, PWM/SPI/fault/enable paths, plus translation metadata for replication.

- [ ] **Step 1: Add failing gate-segment and Kelvin assertions**

Test resistor-to-FET and driver-to-resistor segments separately using pad endpoints rather than total branched-net length. Require F.Cu, zero vias, 10/35 mm limits, all 24 Kelvin pairs present, F.Cu, zero vias, and 2 mm maximum skew.

- [ ] **Step 2: Run the audit on the generated board and verify missing-route failures**

- [ ] **Step 3: Implement deterministic routing primitives**

Implement `add_track(board, net, points_mm, width_mm, layer)` and pad-aware endpoint lookup. Reject a route if it crosses a declared switch-node or isolation keepout.

- [ ] **Step 4: Route Motor 1 in priority order**

Route local source returns, gates, shunt Kelvin pairs, bus-shunt Kelvin pair, CSA/INA outputs to filters, bootstrap/charge-pump paths, PWM, SPI, fault, and enable. Do not add power zones yet.

- [ ] **Step 5: Run sensitive-route audits and DRC**

Expected: all Motor 1 gate and Kelvin checks pass with zero geometric violations in the cell.

- [ ] **Step 6: Commit**

Commit: `git commit -m "feat: route ESC gate and current-sense corridors"`

### Task 5: Replicate sensitive routing and add local power copper

**Files:**
- Modify: `tools/hardware/route_rev_b_sections.py`
- Modify: `tools/hardware/generate_rev_b_pcbs.py`
- Modify: `tools/hardware/audit_rev_b_pcb.py`
- Regenerate: `hardware/esc/rev_b/esc_rev_b.kicad_pcb`

**Interfaces:**
- Consumes: validated Motor 1 geometry and `mapped_net_name(source, motor)`.
- Produces: six identically constrained sensitive-route sets and cell-local F.Cu/In1.Cu/In2.Cu/B.Cu polygons/via fields.

- [ ] **Step 1: Add failing replication and cell-isolation tests**

Require identical route fingerprints after translation, motor-scoped target nets, no foreign motor nets inside a cell, and no shared BATP/BATN polygon between cells.

- [ ] **Step 2: Replicate routes with per-motor net mapping**

Translate Motor 1 tracks to Motors 2–6 while preserving widths, layers, endpoints, and no-via policy. Abort on missing or ambiguous target nets.

- [ ] **Step 3: Add power polygons after sensitive routing**

Use In1.Cu for local BATP, B.Cu for local BATN, In2.Cu for phase paths, and minimal F.Cu device landings. Clip zones around quiet corridors, isolation boundaries, and heatsink fasteners.

- [ ] **Step 4: Add and validate power-via fields**

Keep holes clear of TOLT gates and Kelvin pads. Record via drill, annulus, count, and fabricator assumptions in generated metadata.

- [ ] **Step 5: Fill zones and run full sensitive-route audit**

Expected: all 72 gate nets and all 24 Kelvin pairs pass; six cell-isolation checks pass.

- [ ] **Step 6: Commit**

Commit: `git commit -m "feat: add isolated 60 amp ESC power cells"`

### Task 6: Complete remaining routing under the 500 MB heap cap

**Files:**
- Modify: `tools/hardware/route_rev_b_sections.py`
- Create: `tools/hardware/route_compact_esc.ps1`
- Regenerate: `hardware/esc/rev_b/esc_rev_b.kicad_pcb`
- Create: `hardware/esc/rev_b/reports/esc_rev_b_router_summary.json`

**Interfaces:**
- Consumes: sensitive-routed, power-zone-free or selectively stripped board.
- Produces: completed non-sensitive routing merged without changing locked sensitive tracks.

- [ ] **Step 1: Export a Motor 1 DSN with sensitive routes locked and power planes filtered**

- [ ] **Step 2: Run FreeRouting with the heap cap**

The PowerShell wrapper must invoke Java with `-Xmx500m`, capture the command line, exit code, pass count, unrouted count, and peak reported heap in JSON, and fail if the cap is absent.

- [ ] **Step 3: Import the candidate and reject sensitive-route changes**

Compare sensitive-route fingerprints before and after import. Any moved gate/Kelvin track rejects the candidate.

- [ ] **Step 4: Replicate completed cell routing and route supervisor/power strip**

- [ ] **Step 5: Iterate until the filled full board reports zero unconnected items**

Do not accept an autorouter plateau as completion. Repair residual routes deterministically or adjust placement while preserving prior gates.

- [ ] **Step 6: Commit**

Commit: `git commit -m "feat: complete compact ESC routing"`

### Task 7: Run electrical, thermal, and fabrication validation

**Files:**
- Modify: `docs/hardware/REV_B_ARCHITECTURE.md`
- Modify: `docs/hardware/VALIDATION_MATRIX.md`
- Create: `docs/hardware/ESC_REV_B_THERMAL_MECHANICAL.md`
- Create: `hardware/esc/rev_b/reports/esc_rev_b_layout_audit.json`
- Create: `hardware/esc/rev_b/reports/esc_rev_b_final_drc.json`
- Update: `hardware/esc/rev_b/reports/esc_rev_b_erc.rpt`

**Interfaces:**
- Consumes: filled release PCB and authoritative component/reference-design constraints.
- Produces: reproducible pass/fail reports plus explicit bench-validation items that cannot be proven from CAD.

- [ ] **Step 1: Run netlist connectivity audit and ERC**

Expected: connectivity PASS and zero ERC errors.

- [ ] **Step 2: Run KiCad DRC on the filled board**

Expected: zero violations and zero unconnected items.

- [ ] **Step 3: Run the project-specific layout audit**

Expected: outline, component side, cell separation, gate, Kelvin, RF/isolation, track, and via checks all pass.

- [ ] **Step 4: Document calculable limits and mandatory bench gates**

Record current-density/voltage-drop assumptions, MOSFET loss bounds, shunt dissipation, connector/fuse ratings, TOLT front interface, insulated rear interface, and required double-pulse/thermal tests. Do not label unperformed physical tests as passed.

- [ ] **Step 5: Commit**

Commit: `git commit -m "docs: validate compact ESC fabrication design"`
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

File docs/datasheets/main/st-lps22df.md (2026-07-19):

Title: Datasheet - LPS22DF - Low-power and high-precision MEMS nano pressure sensor: 260-1260 hPa absolute digital output barometer

URL Source: http://www.st.com/resource/en/datasheet/lps22df.pdf

Number of Pages: 53

Markdown Content:
Features 

• 260 to 1260 hPa absolute pressure range 

• Supply current down to 1.7 μA 

• Absolute pressure accuracy: 0.2 hPa 

• Robustness to soldering stress: 0.15 hPa 

• Low pressure sensor noise: 0.34 Pa 

• High-performance TCO: 0.45 Pa/°C 

• Embedded temperature compensation 

• 24-bit pressure data output 

• ODR from 1 Hz to 200 Hz 

• SPI, I²C, or MIPI I3C SM  interface 

• Supports 1.08 V digital interface 

• Embedded FIFO 

• Interrupt functions: data-ready, FIFO flags, pressure thresholds 

• Supply voltage: 1.7 to 3.6 V 

• High shock survivability: 22,000  g

• Small and thin package
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

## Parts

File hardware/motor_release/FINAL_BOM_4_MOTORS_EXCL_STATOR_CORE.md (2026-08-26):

# Final Retail BOM — Four Prototype Motors

Date: 2026-08-26

Scope: four 12-slot / 8-pole outrunner prototype motors. Stator electrical-steel sheets and stator-lamination cutting are intentionally excluded. This BOM follows the current conversation-level geometry (42 mm stator OD, 20 mm active stack, 62 mm maximum motor OD, 45 mm maximum mechanical height, 8 mm shaft) and supersedes the obsolete 51 mm OD / 56 mm stack quantities in the older release package.

## Frozen or selected items

| Item | Specification | Purchase quantity for four motors | Unit price (INR) | Extended price (INR) | Status / notes |
|---|---|---:|---:|---:|---|
| Rotor magnets | 20 x 10 x 2 mm, N42 NdFeB, one layer, 8 poles per motor | 50 pieces | 42.80 | 2,140 | 32 installed; 18 spare for grading, matching and breakage. Measure Br consistency and reject damaged plating. |
| Rotor flux-liner sheet | 0.5 mm ungalvanized cold-rolled mild steel, approximately 300 x 600 mm | 1 sheet | 1,400 | 1,400 | Frozen choice. Form two nested liner layers per rotor with offset seams. One sheet is ample for four rotors and coupons. |
| Shaft stock | 8 mm ground steel round, 500 mm long | 1 rod | 315 | 315 | Free shaft machining assumed. Verify straightness, hardness, bearing fits and final shoulder geometry. |
| Bearings | 608ZZ, 8 x 22 x 7 mm | 10 pieces | 30 | 300 | Eight installed plus two spare. Generic bearings require speed, grease, clearance and runout screening before 35 krpm use. |
| Slot insulation | Nomex, 7 mil (approximately 0.178 mm), 900 x 300 mm | 2 sheets | 270 | 540 | One may be enough geometrically; two allows forming trials, slot liners, phase separators and rejects. |
| Winding impregnation varnish | Elantas V2603 or exact selected Class-H-compatible grade | 1 litre | 1,000 | 1,000 | Confirm exact TDS, cure schedule and compatibility with Nomex and wire enamel. |
| Winding thermistors | 10 k NTC, selected B-value; three per motor | 12 pieces | 6 | 72 | Add four spares if the seller permits. Electrically isolate and calibrate assembled sensors. |
| Hall sensors | Exact selected Hall switch, three per motor | 12 pieces | 62 | 744 | Product identity and electrical interface must be frozen before purchase. Omit if the final controller is sensorless. |
| End-cap / fillet adhesive | Lapox Ultra, 180 g | 1 kit | 349 Amazon / about 211 alternate | 349 budgeted | For keyed end-cap joints and fillets, not fibre impregnation. Maintain 100:80 mass ratio and thin controlled bond lines. |
| Thin magnet adhesive | User-selected small-pack Araldite from Amazon | 1 kit | TBD | TBD | Use only after steel-to-NdFeB lap/shear and thermal-cycle coupons. Remove plating contamination and control bond-line thickness. |
| Composite matrix | Lapox L-12 resin + AH-411 hardener, 100:22 by mass | 1.0 kg resin + 0.22-0.25 kg hardener | 800-1,800 per usable set | 800-1,800 | Primary inner-glass / UD-carbon / outer-glass matrix. Post-cure empty liner/sleeve before magnets are installed. |
| UD hoop reinforcement | 12K UD carbon cloth/tape, approximately 300 gsm | Minimum 1 m x 0.3-0.5 m usable area | TBD | TBD | Circumferential primary retention reinforcement. Purchase enough for four rings plus at least three witness rings. |
| Glass isolation and outer ply | Light woven E-glass cloth, approximately 100-200 gsm | Approximately 1 square metre | TBD | TBD | One inner electrical-isolation ply and one outer handling/damage-indication ply minimum. |
| Phase leads and connectors | Existing stock | 4 motor sets | Free | 0 | Three phase leads per motor; exact gauge and strain relief remain dependent on current and termination geometry. |
| Magnet installation adhesive already in stock | Existing stock, if retained as alternate | As available | Free | 0 | Compare against Araldite coupons; do not stack incompatible adhesive systems in one bond line. |
| Aluminium stock | 6061-T6 for four stator carriers and four rotor end caps | Final CAD-dependent | TBD | TBD | Obtain after corrected CAD fixes blank diameters, axial lengths, bearing seats and cooling ducts. |
| Stator-carrier machining | Four identical 6061-T6 parts | 4 | Quote pending | TBD | Seek one setup plus four-piece batch pricing. |
| Rotor-end-cap machining | Four identical 6061-T6 parts | 4 | Quote pending | TBD | Carbon/steel liner design removes the former fully machined rotor bell. |
| Composite spacers / assembly fixtures | High-temperature printed polymer or machined fixture material | 1 set | TBD | TBD | Printed magnet spacers are retained in the rotor; cure and balance fixtures must tolerate the selected post-cure. |
| Balancing material | Small removable balance weights or qualified balancing compound | 1 kit | TBD | TBD | Do not use random resin blobs as the first balancing method. |
| Shaft retaining hardware | Prop adapter/nut, spacers, washers and retention feature | 4 sets | TBD | TBD | Final shaft and prop interface dependent. |

## Geometry-dependent items that are not yet safe to purchase in bulk

| Item | Present requirement | Why quantity remains open |
|---|---|---|
| Magnet wire | Class H or better, likely parallel 27-32 AWG enamelled copper strands | Turns, strands per turn, mean turn length, phase resistance and slot fill must be recomputed from the corrected 42 mm / 20 mm active geometry. The obsolete 12-AWG and 51 mm-stack figures must not be reused. |
| Aluminium blanks | 6061-T6 | Corrected carrier/end-cap STEP files must freeze bearing seats, ducts, shaft interface and composite overlap before stock size is ordered. |
| Fasteners and retaining rings | Alloy/stainless as appropriate | Sizes depend on the corrected shaft and end-cap drawings. |
| Propeller adapter | For selected 5.5-inch high-speed propeller | Requires final prop hub dimensions and verified shaft/end-cap load path. |

## Explicitly excluded

- CRNO/CRNGO stator electrical-steel sheets.
- Cutting/punching of stator laminations.
- Batteries, ESC/controller, airframe and propellers.
- Free dyno testing, free shaft machining, free phase leads/connectors and any free adhesive already in stock.

## Cost snapshot

Known-price subtotal, excluding the stator core, wire, carbon/glass fabric, aluminium and machining: **INR 6,860**.

Including the expected Lapox L-12/AH-411 matrix purchase: **INR 7,660-8,660**.

This is not the finished-project total. The dominant unresolved costs are aluminium/CNC work, winding copper, carbon/glass reinforcement, fixtures and high-speed-rated bearing replacement if the INR 30 608ZZ samples fail screening.

## Loctite EA E-30CL disposition

Do not use EA E-30CL as the sleeve laminating resin. Henkel identifies it as a 2:1 cartridge structural epoxy with approximately 10,000 cP mixed viscosity, 30-minute work life and approximately 70 C glass-transition temperature. It is useful only as an optional clear joint adhesive after coupon testing. It also requires the correct 2:1 cartridge gun and static mixing nozzles, adding cost and waste.

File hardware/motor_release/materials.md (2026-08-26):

# Materials Specification — Superseded Custom Motor

> **Superseded 2026-08-26:** These materials specify the former custom motor,
> not the purchased Flycci FA4119 platform. See
> [FA4119_PROPULSION_DECISION.md](FA4119_PROPULSION_DECISION.md). In particular,
> do not purchase the custom stator steel, back iron, bell, shaft or magnets for
> the current prototype.

## Stator laminations

- Grade: M-330-35A (or manufacturer-proposed equivalent, e.g. NO-20/NO-27 class)
- Thickness: 0.35 mm, insulated both sides (C5 or better stacking insulation)
- Stacking factor >= 0.95, welded or riveted stack, burr <= 0.03 mm
- Core loss target at 1.5 T / 400 Hz <= 20 W/kg (electrical frequency at 13 krpm is ~433 Hz)

## Rotor back iron and bell

- Back iron: same M-330-35A lamination pack bonded to the bell
- Bell/housing: 6061-T6 aluminum, hard anodized inside magnet pockets optional
- Magnets bonded with high-temperature structural epoxy (see magnet_specification.md) plus a 0.5 mm steel retaining ring rated to the 16.7 krpm proof speed

## Shaft

- Primary: 42CrMo4 quenched and tempered to 900-1100 MPa UTS
- Alternate: 17-4PH H900 if corrosion resistance prioritized
- Bearing seats ground to tolerance per tolerances.md; runout <= 0.02 mm TIR at prop adapter

## Windings

- Conductor: copper, class H enamel (polyamide-imide topcoat), 3 x 3.15 mm parallel strands per turn
- Slot liners: aramid paper (Nomex 410) 0.25 mm
- Varnish: vacuum pressure impregnation (VPI), class H silicone-modified or polyester-imide resin

## Permanent magnets

See magnet_specification.md. Summary: N42SH NdFeB, Ni-Cu-Ni plated.

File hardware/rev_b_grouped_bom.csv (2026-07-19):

Board | Manufacturer | MPN | Value | Footprint | Quantity | References
ESC Rev-B | Commodity / unspecified | 0 STAR | 0 STAR | Resistor_SMD:R_1206_3216Metric | 1 | R704
ESC Rev-B | Commodity / unspecified | 100k | 100k | Resistor_SMD:R_0603_1608Metric | 61 | R1102, R1104, R1106, R1108, R1110, R1112, R1150, R1151, R1152, R1154, R1202, R1204, R1206, R1208, R1210, R1212, R1250, R1251, R1252, R1254, R1302, R1304, R1306, R1308, R1310, R1312, R1350, R1351, R1352, R1354, R1402, R1404, R1406, R1408, R1410, R1412, R1450, R1451, R1452, R1454, R1502, R1504, R1506, R1508, R1510, R1512, R1550, R1551, R1552, R1554, R1602, R1604, R1606, R1608, R1610, R1612, R1650, R1651, R1652, R1654, R231
ESC Rev-B | Commodity / unspecified | 100n | 100n | Capacitor_SMD:C_0603_1608Metric | 40 | C1161, C1164, C1165, C1175, C1176, C1177, C1261, C1264, C1265, C1275, C1276, C1277, C1361, C1364, C1365, C1375, C1376, C1377, C1461, C1464, C1465, C1475, C1476, C1477, C1561, C1564, C1565, C1575, C1576, C1577, C1661, C1664, C1665, C1675, C1676, C1677, C232, C233, C242, C243
ESC Rev-B | Commodity / unspecified | 100n | 100n | Capacitor_SMD:C_0402_1005Metric | 38 | C1167, C1168, C1169, C1170, C1172, C1267, C1268, C1269, C1270, C1272, C1367, C1368, C1369, C1370, C1372, C1467, C1468, C1469, C1470, C1472, C1567, C1568, C1569, C1570, C1572, C1667, C1668, C1669, C1670, C1672, C205, C206, C207, C208, C209, C210, C211, C212
ESC Rev-B | Commodity / unspecified | 100n 100V | 100n 100V | Capacitor_SMD:C_0603_1608Metric | 6 | C1105, C1205, C1305, C1405, C1505, C1605
ESC Rev-B | Commodity / unspecified | 100n 10V | 100n 10V | Capacitor_SMD:C_0603_1608Metric | 6 | C1107, C1207, C1307, C1407, C1507, C1607
ESC Rev-B | Commodity / unspecified | 10k | 10k | Resistor_SMD:R_0603_1608Metric | 15 | R1153, R1156, R1253, R1256, R1353, R1356, R1453, R1456, R1553, R1556, R1653, R1656, R202, R240, R241
ESC Rev-B | Commodity / unspecified | 10k 0.1% | 10k 0.1% | Resistor_SMD:R_0603_1608Metric | 6 | R1145, R1245, R1345, R1445, R1545, R1645
ESC Rev-B | Commodity / unspecified | 10n | 10n | Capacitor_SMD:C_0603_1608Metric | 1 | C231
ESC Rev-B | Commodity / unspecified | 10n 50V | 10n 50V | Capacitor_SMD:C_0603_1608Metric | 6 | C1150, C1250, C1350, C1450, C1550, C1650
ESC Rev-B | Commodity / unspecified | 10n C0G | 10n C0G | Capacitor_SMD:C_0603_1608Metric | 24 | C1120, C1121, C1122, C1123, C1220, C1221, C1222, C1223, C1320, C1321, C1322, C1323, C1420, C1421, C1422, C1423, C1520, C1521, C1522, C1523, C1620, C1621, C1622, C1623
ESC Rev-B | Commodity / unspecified | 10u 100V | 10u 100V | Capacitor_SMD:C_1210_3225Metric | 44 | C1106, C1131, C1132, C1133, C1134, C1135, C1136, C1206, C1231, C1232, C1233, C1234, C1235, C1236, C1306, C1331, C1332, C1333, C1334, C1335, C1336, C1406, C1431, C1432, C1433, C1434, C1435, C1436, C1506, C1531, C1532, C1533, C1534, C1535, C1536, C1606, C1631, C1632, C1633, C1634, C1635, C1636, C702, C711
ESC Rev-B | Commodity / unspecified | 10u 10V | 10u 10V | Capacitor_SMD:C_0805_2012Metric | 6 | C1160, C1260, C1360, C1460, C1560, C1660
ESC Rev-B | Commodity / unspecified | 120 DNP | 120 DNP | Resistor_SMD:R_0603_1608Metric | 1 | R242
ESC Rev-B | Commodity / unspecified | 12p C0G | 12p C0G | Capacitor_SMD:C_0402_1005Metric | 12 | C1173, C1174, C1273, C1274, C1373, C1374, C1473, C1474, C1573, C1574, C1673, C1674
ESC Rev-B | Commodity / unspecified | 14.3k 1% | 14.3k 1% | Resistor_SMD:R_0603_1608Metric | 2 | R703, R712
ESC Rev-B | Commodity / unspecified | 150k 0.1% | 150k 0.1% | Resistor_SMD:R_1206_3216Metric | 24 | R1140, R1141, R1142, R1143, R1240, R1241, R1242, R1243, R1340, R1341, R1342, R1343, R1440, R1441, R1442, R1443, R1540, R1541, R1542, R1543, R1640, R1641, R1642, R1643
ESC Rev-B | Commodity / unspecified | 15p C0G | 15p C0G | Capacitor_SMD:C_0402_1005Metric | 4 | C213, C214, C240, C241
ESC Rev-B | Commodity / unspecified | 1k | 1k | Resistor_SMD:R_0603_1608Metric | 7 | R1157, R1257, R1357, R1457, R1557, R1657, R203
ESC Rev-B | Commodity / unspecified | 1n C0G | 1n C0G | Capacitor_SMD:C_0603_1608Metric | 1 | C230
ESC Rev-B | Commodity / unspecified | 1u | 1u | Capacitor_SMD:C_0603_1608Metric | 8 | C1171, C1271, C1371, C1471, C1571, C1671, C706, C707
ESC Rev-B | Commodity / unspecified | 1u 10V | 1u 10V | Capacitor_SMD:C_0603_1608Metric | 6 | C1104, C1204, C1304, C1404, C1504, C1604
ESC Rev-B | Commodity / unspecified | 1u 16V | 1u 16V | Capacitor_SMD:C_0603_1608Metric | 12 | C1102, C1103, C1202, C1203, C1302, C1303, C1402, C1403, C1502, C1503, C1602, C1603
ESC Rev-B | Commodity / unspecified | 2.2 | 2.2 | Resistor_SMD:R_0603_1608Metric | 36 | R1101, R1103, R1105, R1107, R1109, R1111, R1201, R1203, R1205, R1207, R1209, R1211, R1301, R1303, R1305, R1307, R1309, R1311, R1401, R1403, R1405, R1407, R1409, R1411, R1501, R1503, R1505, R1507, R1509, R1511, R1601, R1603, R1605, R1607, R1609, R1611
ESC Rev-B | Commodity / unspecified | 2.2n 50V X7R | 2.2n 50V X7R | Capacitor_SMD:C_0603_1608Metric | 2 | C703, C712
ESC Rev-B | Commodity / unspecified | 2.2u 100V X7R | 2.2u 100V X7R | Capacitor_SMD:C_1210_3225Metric | 3 | C700, C701, C710
ESC Rev-B | Commodity / unspecified | 2.2u 10V | 2.2u 10V | Capacitor_SMD:C_0603_1608Metric | 12 | C1162, C1163, C1262, C1263, C1362, C1363, C1462, C1463, C1562, C1563, C1662, C1663
ESC Rev-B | Commodity / unspecified | 226k 1% | 226k 1% | Resistor_SMD:R_0603_1608Metric | 2 | R705, R713
ESC Rev-B | Commodity / unspecified | 22u 10V | 22u 10V | Capacitor_SMD:C_1210_3225Metric | 4 | C704, C705, C713, C714
ESC Rev-B | Commodity / unspecified | 3.3n X7R | 3.3n X7R | Capacitor_SMD:C_0603_1608Metric | 2 | C708, C715
ESC Rev-B | Commodity / unspecified | 33 | 33 | Resistor_SMD:R_0402_1005Metric | 1 | R201
ESC Rev-B | Commodity / unspecified | 33k 0.1% | 33k 0.1% | Resistor_SMD:R_0603_1608Metric | 6 | R1144, R1244, R1344, R1444, R1544, R1644
ESC Rev-B | Commodity / unspecified | 33u 1.8A | 33u 1.8A | Inductor_SMD:L_Bourns_SRR1260 | 2 | L701, L702
ESC Rev-B | Commodity / unspecified | 4.7k | 4.7k | Resistor_SMD:R_0603_1608Metric | 6 | R1155, R1255, R1355, R1455, R1555, R1655
ESC Rev-B | Commodity / unspecified | 4.7u | 4.7u | Capacitor_SMD:C_0603_1608Metric | 6 | C1166, C1266, C1366, C1466, C1566, C1666
ESC Rev-B | Commodity / unspecified | 4.7u | 4.7u | Capacitor_SMD:C_0402_1005Metric | 4 | C201, C202, C203, C204
ESC Rev-B | Commodity / unspecified | 41.2k 1% | 41.2k 1% | Resistor_SMD:R_0603_1608Metric | 2 | R701, R710
ESC Rev-B | Commodity / unspecified | 45.3k 1% | 45.3k 1% | Resistor_SMD:R_0603_1608Metric | 2 | R702, R711
ESC Rev-B | Commodity / unspecified | 47 | 47 | Resistor_SMD:R_0603_1608Metric | 24 | R1130, R1131, R1132, R1133, R1230, R1231, R1232, R1233, R1330, R1331, R1332, R1333, R1430, R1431, R1432, R1433, R1530, R1531, R1532, R1533, R1630, R1631, R1632, R1633
ESC Rev-B | Commodity / unspecified | 470p C0G | 470p C0G | Capacitor_SMD:C_0603_1608Metric | 2 | C709, C716
ESC Rev-B | Commodity / unspecified | 47n 100V | 47n 100V | Capacitor_SMD:C_0603_1608Metric | 6 | C1101, C1201, C1301, C1401, C1501, C1601
ESC Rev-B | Commodity / unspecified | ESC_SWD | ESC_SWD | Connector_JST:JST_SH_SM03B-SRSS-TB_1x03-1MP_P1.00mm_Horizontal | 1 | J201
ESC Rev-B | Commodity / unspecified | GREEN | GREEN | LED_SMD:LED_0603_1608Metric | 7 | D1102, D1202, D1302, D1402, D1502, D1602, D201
ESC Rev-B | Commodity / unspecified | LOCAL_SWD | LOCAL_SWD | Connector_PinHeader_1.27mm:PinHeader_1x05_P1.27mm_Vertical | 6 | J1103, J1203, J1303, J1403, J1503, J1603
ESC Rev-B | Abracon | ABM8-272-T3 | 12MHz ABM8-272-T3 | Crystal:Crystal_SMD_3225-4Pin_3.2x2.5mm | 1 | Y201
ESC Rev-B | Abracon | ABM8G-40.000MHZ-10-D2Y-T | 40MHz ABM8G | Crystal:Crystal_SMD_3225-4Pin_3.2x2.5mm | 1 | Y202
ESC Rev-B | Abracon | ABM8G-8.000MHZ-18-D2Y-T | 8MHz ABM8G | Crystal:Crystal_SMD_3225-4Pin_3.2x2.5mm | 6 | Y1101, Y1201, Y1301, Y1401, Y1501, Y1601
ESC Rev-B | Abracon | AOTA-B201610S3R3-101-T | 3.3u AOTA-B201610S3R3-101-T | Inductor_SMD:L_0805_2012Metric | 1 | L201
ESC Rev-B | Bourns | CSS4J-4026R-L500F | 0.5m 1% 10W | revb:CSS4J-4026_Kelvin | 24 | R1120, R1121, R1122, R1123, R1220, R1221, R1222, R1223, R1320, R1321, R1322, R1323, R1420, R1421, R1422, R1423, R1520, R1521, R1522, R1523, R1620, R1621, R1622, R1623
ESC Rev-B | Diodes Inc. | AP2112K-3.3TRG1 | AP2112K-3.3TRG1 | Package_TO_SOT_SMD:SOT-23-5 | 1 | U702
ESC Rev-B | Generic | M5_RING_LUG_PAIR | FUSED_BATTERY_TAP | revb:POWER_LUG_M5_2P_P20 | 6 | J1101, J1201, J1301, J1401, J1501, J1601
ESC Rev-B | Generic | M5_RING_LUG_TRIPLE | MOTOR_PHASES | revb:POWER_LUG_M5_3P_P20 | 6 | J1102, J1202, J1302, J1402, J1502, J1602
ESC Rev-B | Infineon | IPTC014N10NM5ATMA1 | IPTC014N10NM5 | revb:PG-HDSOP-16_TOLT_IPTC | 36 | Q1101, Q1102, Q1103, Q1104, Q1105, Q1106, Q1201, Q1202, Q1203, Q1204, Q1205, Q1206, Q1301, Q1302, Q1303, Q1304, Q1305, Q1306, Q1401, Q1402, Q1403, Q1404, Q1405, Q1406, Q1501, Q1502, Q1503, Q1504, Q1505, Q1506, Q1601, Q1602, Q1603, Q1604, Q1605, Q1606
ESC Rev-B | JST | SM04B-GHS-TB | FLIGHT_CAN_POWER | Connector_JST:JST_GH_SM04B-GHS-TB_1x04-1MP_P1.25mm_Horizontal | 1 | J702
ESC Rev-B | Littelfuse | 1206L075/24WR | PTC 0.75A | Fuse:Fuse_1206_3216Metric | 1 | F701
ESC Rev-B | Littelfuse | SM8S54A | SM8S54A | revb:DO-218AB_SM8S | 7 | D1101, D1201, D1301, D1401, D1501, D1601, D701
ESC Rev-B | Microchip | MCP2518FD-H/QBB | MCP2518FD-H/QBB | Package_DFN_QFN:DFN-14-1EP_3x4.5mm_P0.65mm_EP1.65x4.25mm | 1 | U207
ESC Rev-B | Molex | 43650-0200 | AUX_BATTERY | Connector_Molex:Molex_Micro-Fit_3.0_43650-0200_1x02_P3.00mm_Horizontal | 1 | J701
ESC Rev-B | Murata | BLM18AG601SN1D | 600R@100MHz | Inductor_SMD:L_0603_1608Metric | 7 | FB1101, FB1201, FB1301, FB1401, FB1501, FB1601, FB201
ESC Rev-B | Nexperia | PESD2CANFD24L-T | PESD2CANFD24L-T | Package_TO_SOT_SMD:SOT-23 | 1 | D202
ESC Rev-B | RECOM | RFM-0505S | RFM-0505S | revb:RFM_SIP4_11.5x6_P2.54 | 6 | PS1101, PS1201, PS1301, PS1401, PS1501, PS1601
ESC Rev-B | Raspberry Pi | RP2354B | RP2354B | Package_DFN_QFN:QFN-80-1EP_10x10mm_P0.4mm_EP3.4x3.4mm | 1 | U201
ESC Rev-B | Rubycon | 100PX820MEFC18X35.5 | 820u 100V | Capacitor_THT:CP_Radial_D18.0mm_P7.50mm | 6 | C1130, C1230, C1330, C1430, C1530, C1630
ESC Rev-B | STMicroelectronics | STM32G431CBT6 | STM32G431CBT6 | Package_QFP:LQFP-48_7x7mm_P0.5mm | 6 | U1102, U1202, U1302, U1402, U1502, U1602
ESC Rev-B | TDK | ACT45B-110-2P-TL003 | ACT45B-110-2P-TL003 | Inductor_SMD:L_CommonModeChoke_Coilank_ACM4532 | 1 | FL201
ESC Rev-B | TDK | NTCG163JF103FT1 | NTCG163JF103FT1 | Resistor_SMD:R_0603_1608Metric | 6 | TH1, TH2, TH3, TH4, TH5, TH6
ESC Rev-B | Texas Instruments | DRV8353SRTAR | DRV8353SRTAR | revb:WQFN-40-EP_6x6_P0.5 | 6 | U1101, U1201, U1301, U1401, U1501, U1601
ESC Rev-B | Texas Instruments | INA296A2IDR | INA296A2IDR | Package_SO:SOIC-8_3.9x4.9mm_P1.27mm | 6 | U1105, U1205, U1305, U1405, U1505, U1605
ESC Rev-B | Texas Instruments | ISO6731FDWR | ISO6731FDWR | Package_SO:SOIC-16W_7.5x10.3mm_P1.27mm | 6 | U1103, U1203, U1303, U1403, U1503, U1603
ESC Rev-B | Texas Instruments | LM5164DDAR | LM5164DDA | Package_SO:HSOP-8-1EP_3.9x4.9mm_P1.27mm_EP2.41x3.1mm_ThermalVias | 2 | U701, U703
ESC Rev-B | Texas Instruments | SN74LVC1G08DBVR | SN74LVC1G08DBVR | Package_TO_SOT_SMD:SOT-23-5 | 7 | U1106, U1206, U1306, U1406, U1506, U1606, U205
ESC Rev-B | Texas Instruments | TCAN3413DR | TCAN3413DR | Package_SO:SOIC-8_3.9x4.9mm_P1.27mm | 1 | U206
ESC Rev-B | Texas Instruments | TPS3430WDRCR | TPS3430WDRCR | revb:TPS3430_WSON10_EP | 1 | U204
ESC Rev-B | Texas Instruments | TPS70933DBVR | TPS70933DBVR | Package_TO_SOT_SMD:SOT-23-5 | 6 | U1104, U1204, U1304, U1404, U1504, U1604
Flight Control Rev-B | Commodity / unspecified | 0 (non-SigFox) | 0 (non-SigFox) | Resistor_SMD:R_0402_1005Metric | 1 | R42
Flight Control Rev-B | Commodity / unspecified | 0 STAR | 0 STAR | Resistor_SMD:R_1206_3216Metric | 1 | R3
Flight Control Rev-B | Commodity / unspecified | 0.8p C0G | 0.8p C0G | Capacitor_SMD:C_0402_1005Metric | 1 | C88
Flight Control Rev-B | Commodity / unspecified | 1.8n U2J | 1.8n U2J | Capacitor_SMD:C_0402_1005Metric | 1 | C87
Flight Control Rev-B | Commodity / unspecified | 10 | 10 | Resistor_SMD:R_0402_1005Metric | 1 | R41
Flight Control Rev-B | Commodity / unspecified | 100 | 100 | Resistor_SMD:R_0603_1608Metric | 1 | R32
Flight Control Rev-B | Commodity / unspecified | 100k | 100k | Resistor_SMD:R_0603_1608Metric | 1 | R33
Flight Control Rev-B | Commodity / unspecified | 100k | 100k | Resistor_SMD:R_0402_1005Metric | 3 | R45, R46, R47
Flight Control Rev-B | Commodity / unspecified | 100k 1% | 100k 1% | Resistor_SMD:R_0402_1005Metric | 1 | R7
Flight Control Rev-B | Commodity / unspecified | 100n | 100n | Capacitor_SMD:C_0402_1005Metric | 18 | C101, C115, C30, C31, C32, C33, C34, C35, C36, C37, C38, C39, C40, C41, C50, C52, C54, C56
Flight Control Rev-B | Commodity / unspecified | 100n | 100n | Capacitor_SMD:C_0603_1608Metric | 4 | C122, C123, C70, C72
Flight Control Rev-B | Commodity / unspecified | 100p | 100p | Capacitor_SMD:C_0402_1005Metric | 1 | C106
Flight Control Rev-B | Commodity / unspecified | 10k | 10k | Resistor_SMD:R_0603_1608Metric | 7 | R12, R120, R121, R22, R23, R30, R34
Flight Control Rev-B | Commodity / unspecified | 10k | 10k | Resistor_SMD:R_0402_1005Metric | 2 | R43, R44
Flight Control Rev-B | Commodity / unspecified | 10n | 10n | Capacitor_SMD:C_0402_1005Metric | 2 | C105, C81
Flight Control Rev-B | Commodity / unspecified | 10u | 10u | Capacitor_SMD:C_0603_1608Metric | 2 | C110, C71
Flight Control Rev-B | Commodity / unspecified | 10u 10V | 10u 10V | Capacitor_SMD:C_0805_2012Metric | 2 | C2, C6
Flight Control Rev-B | Commodity / unspecified | 120 DNP | 120 DNP | Resistor_SMD:R_0603_1608Metric | 1 | R122
Flight Control Rev-B | Commodity / unspecified | 12p C0G | 12p C0G | Capacitor_SMD:C_0402_1005Metric | 2 | C92, C93
Flight Control Rev-B | Commodity / unspecified | 15p C0G | 15p C0G | Capacitor_SMD:C_0402_1005Metric | 6 | C120, C121, C20, C21, C86, C89
Flight Control Rev-B | Commodity / unspecified | 1M | 1M | Resistor_SMD:R_0603_1608Metric | 1 | R5
Flight Control Rev-B | Commodity / unspecified | 1k | 1k | Resistor_SMD:R_0603_1608Metric | 1 | R13
Flight Control Rev-B | Commodity / unspecified | 1n | 1n | Capacitor_SMD:C_0402_1005Metric | 1 | C113
Flight Control Rev-B | Commodity / unspecified | 1u | 1u | Capacitor_SMD:C_0603_1608Metric | 3 | C114, C3, C4
Flight Control Rev-B | Commodity / unspecified | 2.2u | 2.2u | Capacitor_SMD:C_0603_1608Metric | 5 | C100, C51, C53, C55, C57
Flight Control Rev-B | Commodity / unspecified | 2.4p DNP | 2.4p DNP | Capacitor_SMD:C_0402_1005Metric | 1 | C94
Flight Control Rev-B | Commodity / unspecified | 2.7p DNP | 2.7p DNP | Capacitor_SMD:C_0402_1005Metric | 1 | C96
Flight Control Rev-B | Commodity / unspecified | 220n | 220n | Capacitor_SMD:C_0402_1005Metric | 1 | C80
Flight Control Rev-B | Commodity / unspecified | 22p C0G | 22p C0G | Capacitor_SMD:C_0402_1005Metric | 1 | C84
Flight Control Rev-B | Commodity / unspecified | 27 | 27 | Resistor_SMD:R_0402_1005Metric | 2 | R10, R11
Flight Control Rev-B | Commodity / unspecified | 27p | 27p | Capacitor_SMD:C_0402_1005Metric | 1 | C111
Flight Control Rev-B | Commodity / unspecified | 3.3k | 3.3k | Resistor_SMD:R_0402_1005Metric | 1 | R50
Flight Control Rev-B | Commodity / unspecified | 3.3p C0G | 3.3p C0G | Capacitor_SMD:C_0402_1005Metric | 1 | C91
Flight Control Rev-B | Commodity / unspecified | 33 | 33 | Resistor_SMD:R_0402_1005Metric | 1 | R4
Flight Control Rev-B | Commodity / unspecified | 33p C0G | 33p C0G | Capacitor_SMD:C_0402_1005Metric | 1 | C85
Flight Control Rev-B | Commodity / unspecified | 4.7k | 4.7k | Resistor_SMD:R_0603_1608Metric | 2 | R20, R21
Flight Control Rev-B | Commodity / unspecified | 4.7n 2kV | 4.7n 2kV | Capacitor_SMD:C_1206_3216Metric | 1 | C5
Flight Control Rev-B | Commodity / unspecified | 4.7u | 4.7u | Capacitor_SMD:C_0402_1005Metric | 4 | C10, C11, C12, C13
Flight Control Rev-B | Commodity / unspecified | 4.7u 10V | 4.7u 10V | Capacitor_SMD:C_0805_2012Metric | 1 | C1
Flight Control Rev-B | Commodity / unspecified | 453k 1% | 453k 1% | Resistor_SMD:R_0402_1005Metric | 1 | R6
Flight Control Rev-B | Commodity / unspecified | 47 | 47 | Resistor_SMD:R_0402_1005Metric | 1 | R51
Flight Control Rev-B | Commodity / unspecified | 47n | 47n | Capacitor_SMD:C_0402_1005Metric | 5 | C102, C103, C104, C82, C83
Flight Control Rev-B | Commodity / unspecified | 47p | 47p | Capacitor_SMD:C_0402_1005Metric | 1 | C112
Flight Control Rev-B | Commodity / unspecified | 47p C0G | 47p C0G | Capacitor_SMD:C_0402_1005Metric | 1 | C90
Flight Control Rev-B | Commodity / unspecified | 5.1k | 5.1k | Resistor_SMD:R_0603_1608Metric | 2 | R1, R2
Flight Control Rev-B | Commodity / unspecified | 56k | 56k | Resistor_SMD:R_0603_1608Metric | 1 | R31
Flight Control Rev-B | Commodity / unspecified | 56k | 56k | Resistor_SMD:R_0402_1005Metric | 1 | R40
Flight Control Rev-B | Commodity / unspecified | 600R@100MHz | 600R@100MHz | Inductor_SMD:L_0603_1608Metric | 1 | FB20
Flight Control Rev-B | Commodity / unspecified | 7.5p C0G | 7.5p C0G | Capacitor_SMD:C_0402_1005Metric | 1 | C95
Flight Control Rev-B | Commodity / unspecified | GREEN | GREEN | LED_SMD:LED_0603_1608Metric | 1 | D10
Flight Control Rev-B | Commodity / unspecified | SWD | SWD | Connector_JST:JST_SH_SM03B-SRSS-TB_1x03-1MP_P1.00mm_Horizontal | 1 | J10
Flight Control Rev-B | Abracon | ABM8-272-T3 | 12MHz ABM8-272-T3 | Crystal:Crystal_SMD_3225-4Pin_3.2x2.5mm | 1 | Y1
Flight Control Rev-B | Abracon | ABM8G-40.000MHZ-10-D2Y-T | 40MHz ABM8G | Crystal:Crystal_SMD_3225-4Pin_3.2x2.5mm | 1 | Y50
Flight Control Rev-B | Abracon | AOTA-B201610S3R3-101-T | 3.3u AOTA-B201610S3R3-101-T | Inductor_SMD:L_0805_2012Metric | 1 | L1
Flight Control Rev-B | GCT | USB4105-GF-A | USB-C USB2 | Connector_USB:USB_C_Receptacle_GCT_USB4105-xx-A_16P_TopMnt_Horizontal | 1 | J1
Flight Control Rev-B | Hirose | U.FL-R-SMT-1(10) | 915MHz_ANT | Connector_Coaxial:U.FL_Hirose_U.FL-R-SMT-1_Vertical | 1 | J40
Flight Control Rev-B | Hirose | U.FL-R-SMT-1(10) | GNSS_UFL | Connector_Coaxial:U.FL_Hirose_U.FL-R-SMT-1_Vertical | 1 | J30
Flight Control Rev-B | JST | SM04B-GHS-TB | ESC_CAN_POWER | Connector_JST:JST_GH_SM04B-GHS-TB_1x04-1MP_P1.25mm_Horizontal | 1 | J2
Flight Control Rev-B | Littelfuse | 1206L075/24WR | PTC 0.75A | Fuse:Fuse_1206_3216Metric | 1 | F1
Flight Control Rev-B | Microchip | MCP2518FD-H/QBB | MCP2518FD-H/QBB | Package_DFN_QFN:DFN-14-1EP_3x4.5mm_P0.65mm_EP1.65x4.25mm | 1 | U51
Flight Control Rev-B | Murata | BLM15HG102SN1D | 1k@100MHz | Inductor_SMD:L_0402_1005Metric | 1 | L40
Flight Control Rev-B | Murata | BLM18AG601SN1D | 600R@100MHz | Inductor_SMD:L_0603_1608Metric | 1 | FB1
Flight Control Rev-B | Murata | LFD21868MMF1D386 | LFD21868MMF1D386 | revb:LFD21868MMF1D386 | 1 | FL40
Flight Control Rev-B | Murata | LQG15HS1N5S02D | 1.5n | Inductor_SMD:L_0402_1005Metric | 1 | L43
Flight Control Rev-B | Murata | LQW15AN10NJ00D | 10n | Inductor_SMD:L_0402_1005Metric | 2 | L42, L45
Flight Control Rev-B | Murata | LQW15AN15NJ00D | 15n | Inductor_SMD:L_0402_1005Metric | 1 | L44
Flight Control Rev-B | Murata | LQW15AN2N9C00D | 2.9n | Inductor_SMD:L_0402_1005Metric | 1 | L48
Flight Control Rev-B | Murata | LQW15AN7N5G00D | 7.5n | Inductor_SMD:L_0402_1005Metric | 1 | L47
Flight Control Rev-B | Murata | LQW15AN8N2G00D | 8.2n | Inductor_SMD:L_0402_1005Metric | 1 | L41
Flight Control Rev-B | Murata | LQW15AN9N1G00D | 9.1n | Inductor_SMD:L_0402_1005Metric | 1 | L49
Flight Control Rev-B | Murata | LQW18AN22NJ10D | 22n | Inductor_SMD:L_0603_1608Metric | 1 | L46
Flight Control Rev-B | NDK | NT2016SA-32M-TEE3017A | 32MHz NT2016SA-32M-TEE3017A | Oscillator:Oscillator_SMD_SiT_PQFN-4Pin_2.0x1.6mm | 1 | Y40
Flight Control Rev-B | Nexperia | 2N7002P | 2N7002 | Package_TO_SOT_SMD:SOT-23 | 1 | Q30
Flight Control Rev-B | Nexperia | PESD2CANFD24L-T | PESD2CANFD24L-T | Package_TO_SOT_SMD:SOT-23 | 1 | D50
Flight Control Rev-B | Nexperia | PMEG2010ER | PMEG2010ER | Diode_SMD:D_SOD-123 | 2 | D1, D2
Flight Control Rev-B | Quectel | LG77LICMD | LG77LICMD | revb:LG77L_LGA43 | 1 | U30
Flight Control Rev-B | Raspberry Pi | RP2354B | RP2354B | Package_DFN_QFN:QFN-80-1EP_10x10mm_P0.4mm_EP3.4x3.4mm | 1 | U10
Flight Control Rev-B | STMicroelectronics | LPS22DFTR | LPS22DFTR | Package_LGA:ST_HLGA-10_2x2mm_P0.5mm_LayoutBorder3x2y | 1 | U22
Flight Control Rev-B | STMicroelectronics | LSM6DSO32TR | LSM6DSO32TR | revb:LSM6DSO32_LGA14 | 1 | U21
Flight Control Rev-B | STMicroelectronics | USBLC6-2SC6 | USBLC6-2SC6 | Package_TO_SOT_SMD:SOT-23-6 | 1 | U1
Flight Control Rev-B | TDK | ACT45B-110-2P-TL003 | ACT45B-110-2P-TL003 | Inductor_SMD:L_CommonModeChoke_Coilank_ACM4532 | 1 | FL50
Flight Control Rev-B | TDK EPCOS | B39921B3588U410 | B39921B3588U410 | revb:RF_Filter_4Port | 1 | FL41
Flight Control Rev-B | TDK InvenSense | ICM-42688-P | ICM-42688-P | revb:ICM42688P_LGA14 | 1 | U20
Flight Control Rev-B | Taiyo Yuden | NR4018T2R2M | 2.2u 3.5A | Inductor_SMD:L_APV_ANR4018 | 1 | L2
Flight Control Rev-B | Texas Instruments | CC1121RHBR | CC1121RHBR | Package_DFN_QFN:Texas_RHB0032E_VQFN-32-1EP_5x5mm_P0.5mm_EP3.45x3.45mm_ThermalVias | 1 | U40
Flight Control Rev-B | Texas Instruments | CC1190RGVR | CC1190RGVR | Package_DFN_QFN:Texas_RGV0016A_VQFN-16-1EP_4x4mm_P0.65mm_EP2.1x2.1mm_ThermalVias | 1 | U41
Flight Control Rev-B | Texas Instruments | TCAN3413DR | TCAN3413DR | Package_SO:SOIC-8_3.9x4.9mm_P1.27mm | 1 | U50
Flight Control Rev-B | Texas Instruments | TLV62569DBVR | TLV62569DBVR | Package_TO_SOT_SMD:SOT-23-5 | 1 | U2
Flight Control Rev-B | Texas Instruments | TLV75528PDBVR | TLV75528PDBVR | Package_TO_SOT_SMD:SOT-23-5 | 1 | U3

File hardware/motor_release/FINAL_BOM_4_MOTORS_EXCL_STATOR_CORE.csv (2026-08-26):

category | item | specification | purchase_qty | unit_price_inr | extended_price_inr | status
rotor | Rotor magnets | 20x10x2 mm N42 NdFeB; 8 poles/motor | 50 | 42.80 | 2140 | 32 installed; 18 spares
rotor | Rotor flux-liner sheet | 0.5 mm ungalvanized cold-rolled mild steel; approx 300x600 mm | 1 | 1400 | 1400 | Frozen; two nested layers per rotor
rotor | Shaft stock | 8 mm ground steel; 500 mm | 1 | 315 | 315 | Free machining assumed
rotor | Bearings | 608ZZ 8x22x7 mm | 10 | 30 | 300 | Eight installed plus two spare; high-speed screening required
insulation | Nomex | 7 mil; 900x300 mm | 2 | 270 | 540 | Allows liners separators trials and rejects
insulation | Winding impregnation varnish | Elantas V2603 or exact selected Class-H-compatible grade; 1 L | 1 | 1000 | 1000 | Confirm TDS and cure compatibility
sensors | Thermistors | 10k NTC; three per motor | 12 | 6 | 72 | Calibration required
sensors | Hall sensors | Exact part TBD; three per motor | 12 | 62 | 744 | Omit if final controller is sensorless
adhesive | Lapox Ultra | 180 g kit | 1 | 349 | 349 | End-cap keyed joint and fillets only
adhesive | Araldite Amazon kit | Exact consumer structural adhesive | 1 | TBD | TBD | Magnet bond only after coupons
composite | Lapox L-12 plus AH-411 | 100:22 by mass; 1.0 kg resin plus 0.22-0.25 kg hardener | 1 | 800-1800 | 800-1800 | Primary sleeve matrix; post-cure before magnets
composite | UD carbon cloth or tape | 12K; approx 300 gsm | TBD | TBD | TBD | Hoop reinforcement plus witness rings
composite | Woven E-glass cloth | 100-200 gsm; approx 1 square metre | 1 | TBD | TBD | Inner isolation and outer protection
winding | Class-H magnet wire | Parallel 27-32 AWG enamelled copper; exact turns and length pending | TBD | TBD | TBD | Do not buy bulk until winding is recomputed
machined | 6061-T6 aluminium stock | Four stator carriers and four rotor end caps | TBD | TBD | TBD | Corrected CAD dependent
machined | Stator-carrier CNC | Four identical parts | 4 | TBD | TBD | Batch quote required
machined | Rotor-end-cap CNC | Four identical parts | 4 | TBD | TBD | Batch quote required
hardware | Phase leads and connectors | Existing stock; four motor sets | 4 | 0 | 0 | Free
hardware | Retaining hardware and prop adapters | Final CAD and prop dependent | 4 | TBD | TBD | Not frozen
fixtures | Composite and magnet fixtures | High-temperature cure and assembly fixtures | 1 | TBD | TBD | Cure tooling cannot be ordinary PLA
service | Shaft machining | Four shafts | 4 | 0 | 0 | Free
service | Dyno testing | Four motors plus proof sequence | 4 | 0 | 0 | Free; guarded proof spin still required

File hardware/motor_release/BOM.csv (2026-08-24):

item | description | specification | qty | material_source | notes
1 | Stator lamination stack | M-330-35A 0.35mm 24-slot 51.0mm OD | 1 | lamination house | see stator_lamination.dxf
2 | Stator winding | 3 x 3.15mm class-H Cu per turn double-layer concentrated | 1 set | winding shop | see winding_table.csv
3 | Permanent magnets | N42SH NdFeB arc segments 8-pole 6.5mm radial | 8 | magnet supplier | see magnet_specification.md
4 | Magnet bonding epoxy | high-temp structural adhesive class H rated | 1 tube | adhesive supplier | bond line 0.10mm nominal
5 | Magnet retaining ring | 0.5mm spring steel strap or bell lip crimp | 1 | metalwork | hoop SF >= 2 at proof speed
6 | Rotor bell | 6061-T6 aluminum | 1 | CNC machined | integral back iron seat
7 | Shaft | 42CrMo4 QT 8mm diameter | 1 | turned and ground | see shaft_drawing.pdf
8 | Bearing front | 6901-2RS 12x24x6 mm thin section | 1 | bearing supplier | prop end thrust and radial
9 | Bearing rear | 685-2RS 5x11x3 mm extra thin section | 1 | bearing supplier | cold-end axial location
10 | Preload wave washer | stainless wave washer for rear bearing | 1 | standard part | light axial preload
11 | Stator housing | 6061-T6 aluminum with cooling fins optional | 1 | CNC machined | H7/g6 stator press fit
12 | Slot liners | Nomex 410 0.25mm cut insulators | 24 set | laser cut | class H insulation
13 | VPI varnish | class H polyester-imide resin | as needed | chemical supplier | vacuum pressure impregnation
14 | Temperature sensor | NTC thermistor 10k B3435 end-turn mounted | 3 | sensor supplier | winding overtemp protection
15 | Lead wires | 12 AWG silicone insulated 150mm | 3 | cable supplier | phase leads U V W
16 | Snap rings | DIN 471/472 per bearing seats | 2 | standard part | axial retention

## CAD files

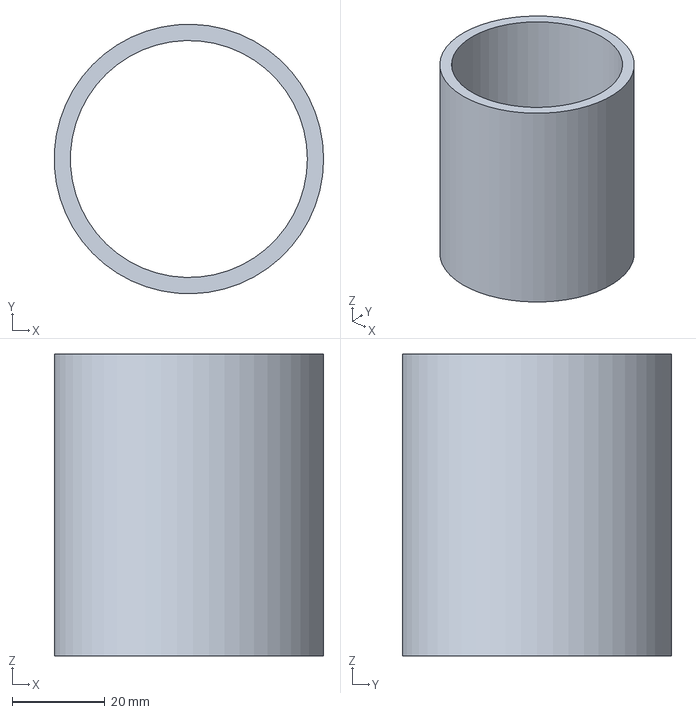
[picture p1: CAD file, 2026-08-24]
hardware/motor_release/stator_housing.step
57.9 x 58.0 x 65.0 mm

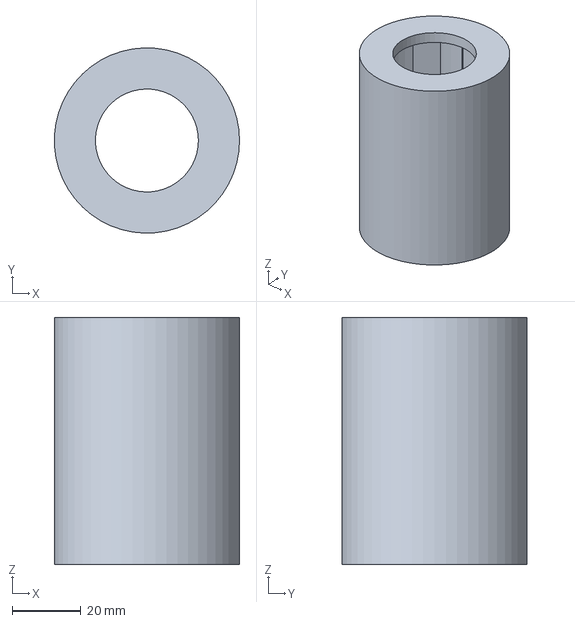
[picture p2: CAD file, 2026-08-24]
hardware/motor_release/rotor_bell.step
53.9 x 54.0 x 72.0 mm

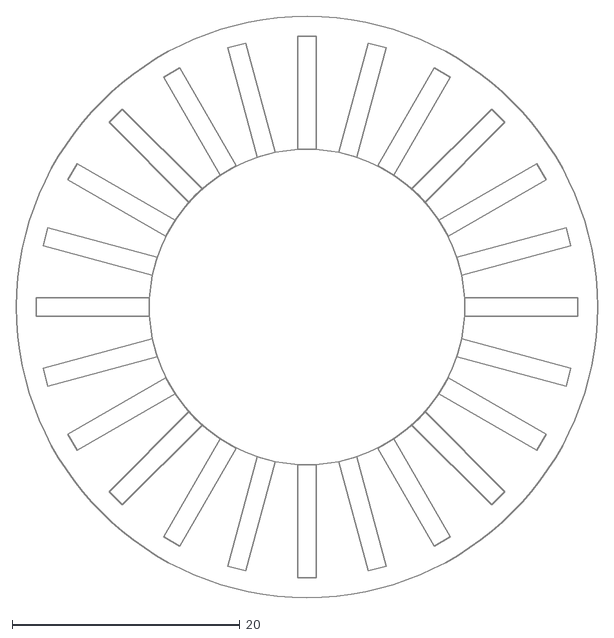
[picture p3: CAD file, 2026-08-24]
hardware/motor_release/stator_lamination.dxf
51.0 x 51.0

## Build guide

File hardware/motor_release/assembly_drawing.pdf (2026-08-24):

ASSEMBLY DRAWING
MOTOR ASSEMBLY - OUTRUNNER BLDC
Stator OD: 51.0 mm [lamination stack]
Bore: 13.84 mm radius; airgap: 0.50 mm
Winding: 24 slots, 8 poles, 3 x 3.15 mm wire, double-layer concentrated Bearings: front 6901-2RS, rear 685-2RS [see bearing_specification.md] Mass budget: see BOM.csv; balance grade G6.3 at rated speed

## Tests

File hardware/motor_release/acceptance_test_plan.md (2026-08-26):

# Acceptance Test Plan — Superseded Custom Motor

> **Superseded 2026-08-26:** The fixed resistance, speed, air-gap and thermal
> values below belong to the older custom motor. Use the staged FA4119 gates in
> [FA4119_PROPULSION_DECISION.md](FA4119_PROPULSION_DECISION.md) for the selected
> prototype. This file remains historical until a measurement-based FA4119
> acceptance plan replaces it.

Every motor (or sample per sampling plan noted) must pass these tests before
shipment. Flight release additionally requires the system-level tests at the end.

## A. Winding and insulation (100% of units)

1. Resistance: measure phase-to-phase cold at 25 C reference; accept 19.7 mOhm +/- 10%.
2. Inductance: LCI bridge at 1 kHz and 10 kHz; record values, compare across units +/- 15%.
3. Insulation: 500 VDC megger, >= 100 MOhm phase-to-frame.
4. Hi-pot: 1.2 kVAC 1 s phase-to-frame, no breakdown.

## B. Back-EMF and magnetics (sampling: first article + every 20th)

1. Spin test at 3000 rpm: line-to-line RMS BEMF per krpm within +/- 7% of model.
2. BEMF waveform capture; THD < 8%; confirm balanced phases within 2%.
3. Pole/slot verification by flux mapping or low-voltage spin scope check.

## C. Mechanical (first article + every 50th)

1. Balance grade verification G6.3 at rated speed on balancing machine.
2. Overspeed spin test: 16,700 rpm for 60 s, room temperature, post-test dye-penetrant on retaining ring and bell.
3. Shaft runout <= 0.02 mm TIR at prop seat after overspeed.
4. Air gap feeler check at 4 quadrants: all readings >= 0.35 mm.
5. Magnet retention pull-off sample test per magnet_specification.md.

## D. Thermal (first article + annual requalification)

1. Thermocouples: 3 x winding end turns, 1 x housing, 1 x bearing front.
2. Continuous soak: design point load to thermal steady state with 10 m/s airflow; winding must stabilize below 130 C at 45 C ambient.
3. Burst transient: 90 A for 30 s from steady state; peak winding temperature below 150 C.
4. Bearing temperature below 90 C throughout.

## E. Performance (every unit, production dyno)

1. Efficiency map spot points at 25/50/75/100% of rated speed at 60 A: measured shaft efficiency recorded; acceptance threshold defined after first-article dyno correlation (analytical estimate is ~96% electromagnetic only).
2. No-load current at 13,000 rpm within manufacturer-correlated limit.
3. Cogging torque qualitative check; audible noise at rated speed recorded.

## F. System-level (flight release gate, on aircraft-integrated motor)

1. ESC FOC autocalibration completes cleanly with this motor (resistance, inductance, flux observer).
2. Locked-rotor, phase-open, and phase-short fault response per REV_B_ARCHITECTURE.md validation list.
3. Regeneration behavior verified against battery charge-acceptance limits.
4. EMI scan with motor running at cruise power alongside GNSS and 915 MHz radio active.

## Acceptance authority

First-article signoff requires the full matrix above witnessed and archived
(data files, thermocouple logs, dyno traces). Production release per sampling
plan requires sections A, E, plus C.3 runout check.

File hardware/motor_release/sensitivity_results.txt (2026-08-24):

Manufacturing tolerance sensitivity - final design
==================================================

Each parameter perturbed by its manufacturing tolerance (both directions);
full safety evaluation rerun per case:

Rint +/- 0.05 mm            SAFE   Tmax=117.1/116.7 C
Rrotor_ext +/- 0.05 mm      SAFE   Tmax=116.9 C both
magnet_thickness +/- 0.10   SAFE   Tmax=116.9 C both
motor_length +/- 0.30 mm    SAFE   Tmax=116.9 C both
wire_diameter +/- 0.02 mm   SAFE   Tmax=115.8/118.0 C

Worst-case combined (min airgap + thin magnets):
  SAFE   Tmax=115.3 C   thermal gap clearance OK

Conclusion: no single or combined realistic manufacturing variation makes the
design unsafe. The nearest margin is winding temperature (118 C worst vs the
120 C magnet limit and 170 C insulation ceiling).

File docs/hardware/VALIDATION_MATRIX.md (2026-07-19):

# Hardware validation matrix

The original hardware remains unapproved. Revision B is a separate corrected
implementation. `PASS` below means the source/netlist/EDA check passed; it is
not a substitute for the physical qualification listed in
`REV_B_ARCHITECTURE.md`.

## Repository and change-source audit

| Check | Result | Evidence |
| --- | --- | --- |
| Latest main | PASS | Fast-forwarded to `origin/main` commit `3b52fbe75671ab1cc6fcc1d298fd52cf6ec10704` before Rev-B work |
| Open hardware PR fix | NONE | No open PR contains a complete electrical correction |
| Closed PR 6 | REJECTED | Mechanical/placeholder routing does not correct the schematics and includes unsafe scripts |
| Other branch | NOT APPLICABLE | `sdk-recreation` is firmware-only |
| Original dirty files | PRESERVED | Rev-B work is confined to new `hardware/*/rev_b`, `docs`, and `tools/hardware` paths |

## Original ESC findings

| Area | Original finding | Revision-B disposition |
| --- | --- | --- |
| IR2136 supply | Driver VCC was 3.3 V although the part requires a gate-drive supply near 10-20 V | Replaced motor stage with DRV8353S |
| PWM independence | Six bridges shared only two input groups | One local STM32G431 and independent TIM1 PWM group per motor |
| Current trip | INA240 midscale conflicted with IR2136 trip threshold | DRV8353S hardware protection plus local ADC plausibility |
| Current acquisition | Remote ADC architecture could not synchronously serve six FOC loops | Three local CSA channels plus one local INA296 bus channel per motor |
| Power switches | Generic/incomplete production definition; IPTC015N10NM5 is discontinued | Infineon's compatible active/preferred IPTC014N10NM5 replacement with the same TOLT pinout |
| Shunts | Undefined value/power and inappropriate footprints | Four CSS4J-4026 0.5 mOhm Kelvin shunts per motor |
| Aggregate feed | PCB was expected to distribute 360 A | Six fused external star/busbar feeds; no common 360 A PCB trunk |
| Return domains | Remote single-ended signals crossed independent BATN references | Only fail-low isolated digital command/arm/status crosses each cell boundary |
| Gate booster | Proposed as a repair for inadequate drive | Not required with DRV8353S; reconsider only after double-pulse measurement |

## Revision-B ESC schematic

| Check | Result | Evidence |
| --- | --- | --- |
| Modular hierarchy | PASS | Top sheet, auxiliary power, supervisor, and six separate motor-cell sheets |
| ERC | PASS | `hardware/esc/rev_b/reports/esc_rev_b_erc.rpt`: zero errors and zero warnings |
| Design-intent connectivity | PASS | Shared audit: 239 checks, zero failures |
| Motor controllers | PASS | Six STM32G431CBT6 |
| Gate drivers | PASS | Six DRV8353SRTAR |
| Power switches | PASS | 36 IPTC014N10NM5, one high and one low switch per phase |
| Leg-current sensing | PASS | 18 low-side 0.5 mOhm Kelvin shunts, all three DRV CSA outputs routed to local ADCs |
| Per-motor current sensing | PASS | Six separate high-side 0.5 mOhm shunts and six INA296A2 bidirectional amplifiers |
| ADC bandwidth | PASS | Four 47 ohm/10 nF outputs per motor to two 4 MSPS STM32 ADCs |
| Hardware break | PASS | Every DRV `nFAULT` reaches STM32 PA11/TIM1_BKIN2 |
| Hardware arm | PASS | `ENABLE = ARM_ISO AND MCU_ARM`, with fail-low pulls |
| Isolation | PASS | No motor MCU, driver, MOSFET, shunt, or local arm-gate node bonds to DGND |
| Isolated power | PASS | RFM-0505S followed by 30 V-input TPS70933, preventing unregulated 5 V output from overvolting 3.3 V logic |
| Isolated LDO enable | PASS | Raw converter output reaches TPS709 `IN`; a local 100 kohm/68 kohm divider keeps `EN` within rating |
| Transient clamp | PASS WITH PHYSICAL TEST REQUIRED | SM8S51A gives 51 V standoff and 82.4 V specified maximum clamp; it is not a sustained-regeneration absorber |
| CAN FD | PASS | MCP2518FD plus TCAN3413, choke, ESD, and optional terminator |
| Auxiliary power | PASS | Two independent LM5164 1 A rails, one internal and one fused for the flight board |
| RP2354B bypass population | PASS | Nine 3.3 V, three DVDD, and one ADC_AVDD high-frequency bypass positions |

## Original flight-control findings

| Area | Original finding | Revision-B disposition |
| --- | --- | --- |
| MCU pins | GPIOs were tied to unrelated supply rails | Correct RP2354B power mapping and internal switcher network |
| USB | Header substituted for USB-C; CC and ESD absent | USB-C receptacle, 5.1 kohm CC pulls, USB ESD |
| GNSS | Interface pins were crossed into IMU SPI | Dedicated GNSS UART |
| Barometer | Interrupt output was tied to ground | Interrupt routed to an MCU GPIO |
| RF DCPL | CC1121 decoupling node was tied to MOSI | Local decoupling only |
| RF matching | Programmable network did not follow a characterized design | Fixed 915 MHz network and U.FL; VNA tuning remains a physical test |
| CAN | No robust ESC command link | MCP2518FD plus TCAN3413 CAN FD |

## Revision-B flight-control schematic

| Check | Result | Evidence |
| --- | --- | --- |
| Distinct board | PASS | No ESC driver, MOSFET, isolation converter, or current-amplifier population |
| Modular hierarchy | PASS | Power/USB, MCU, sensors, GNSS, RF, and CAN sheets |
| ERC | PASS | `hardware/main/rev_b/reports/main_rev_b_erc.rpt`: zero errors and zero warnings |
| CAN controller/transceiver | PASS | MCP2518FD-H/QBB and TCAN3413DR |
| CAN controller path | PASS | SPI/interrupt to RP2354B, TXCAN/RXCAN to transceiver |
| Sensor redundancy | PASS | ICM-42688-P plus LSM6DSO32 retained; LPS22DF barometer present |
| USB | PASS | USB-C USB2 connector, CC pulls, input protection, and ESD |
| GNSS | PASS | LG77L with dedicated UART, local quiet LDOs, always-on backup rail, protected U.FL path, and 3 mm courtyard |
| RF population | PASS WITH PHYSICAL TEST REQUIRED | Fixed CC1121/CC1190 network; VNA/EMI/regulatory verification remains mandatory |
| RP2354B bypass population | PASS | Nine 3.3 V, three DVDD, and one ADC_AVDD high-frequency bypass positions |

## PCB status

| Check | ESC | Flight control |
| --- | --- | --- |
| Board remains distinct | PASS | PASS |
| Explicit four-layer stack | PASS: 4 oz outer, 1.5 oz inner | PASS: four-layer 1 oz baseline |
| Pre-route shorts | PASS: zero | PASS: zero |
| Pre-route copper-clearance violations | PASS: zero | PASS: zero |
| Pre-route courtyard overlaps | PASS: zero | PASS: zero |
| Pre-route illegal zone intersections | PASS: zero | PASS: zero |
| Sensitive placement | PASS | PASS: CAN, GNSS, sensors, CC1121/CC1190 matching and bypass parts are local rather than parked in generic rows |
| Gate placement | PASS: series resistors are about 4.1 mm from gates; longest driver-to-resistor air-line about 27.2 mm | Not applicable |
| Router memory policy | 500 MB Java heap, Serial GC, one optimizer thread | 500 MB Java heap, Serial GC, one optimizer thread |
| Final routing | IN PROGRESS | IN PROGRESS |
| Final DRC | PENDING | PENDING |
| Manufacturing exports | PENDING | PENDING |

## Required bench qualification

The following cannot be proven by KiCad and therefore remain release gates:

- one-channel current-limited bring-up;
- dead-time and hardware-break measurement;
- double-pulse overshoot/switching-loss test;
- current gain/offset/timing calibration;
- 60 A thermal soak with production heat spreader and airflow;
- regenerative, locked-rotor, phase-open/short, and command-loss tests;
- conducted/radiated EMI;
- CAN fault-injection and bus-off recovery;
- GNSS desense test; and
- 915 MHz VNA match plus regional regulatory testing.

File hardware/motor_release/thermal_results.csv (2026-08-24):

time_s | T_winding_C | case
0 | 45.0 | continuous
30 | 48.6 | continuous
60 | 52.1 | continuous
120 | 58.5 | continuous
300 | 73.9 | continuous
600 | 90.8 | continuous
900 | 100.6 | continuous
1200 | 106.4 | continuous
1800 | 111.7 | continuous
10 | 115.8 | burst_from_steady_state
20 | 117.2 | burst_from_steady_state
30 | 118.6 | burst_from_steady_state

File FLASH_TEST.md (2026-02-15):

# Flash Test Implementation Summary

## Changes Made

### 1. Linker Script (src/main_board/linker_script.ld)
Created new linker script that:
- Reserves main flash area: 0x10000000 - 0x101FEFFF (2044KB)
- Reserves test area at end: 0x101FF000 - 0x101FFFFF (4KB)
- Exports `flash_test_region` symbol for C code access

### 2. Flash Test Function (src/main_board/init_clocks.c)
Replaced RAM-based simulation with real flash operations:

**Location:** 0x101FF000 (last 4KB of 2MB flash)

**Operations:**
1. **Sector Erase** (4KB) - Required before writing
   - Sends Write Enable command (0x06)
   - Sends Sector Erase command (0x20) with address
   - Polls status register until complete

2. **Page Program** - Writes test patterns
   - 4 pages × 256 bytes each
   - 32 words per page
   - Uses test patterns: 0xAAAAAAAA, 0x55555555, etc.

3. **Read & Verify** - Reads back and compares
   - Sequential read command (0x03)
   - Compares against expected patterns
   - Tracks errors

**Interface:** Uses QMI (QSPI Memory Interface) direct mode
- Base: 0x400d0000
- CSR: Control/Status Register
- TX: Transmit FIFO
- RX: Receive FIFO

### 3. Test Coverage
- Tests actual flash chip timing at each clock frequency
- Verifies both write and read operations
- Accepts <5% error rate (real flash may have bit errors)

## Flash Map
```
0x10000000 +------------------+
           |                  |
           |   Application    |  2044 KB
           |     Code         |
           |                  |
0x101FF000 +------------------+
           |   Test Region    |  4 KB
           |  (Reserved)      |
0x10200000 +------------------+
```

## Build Integration
Linker script referenced in meson.build:
```meson
link_script = meson.current_source_dir() / 'src/main_board/linker_script.ld'
link_args = ['-T' + link_script, ...]
```

## Safety
- Test region is at end of flash, won't overwrite code
- Sector erase required before write (standard flash procedure)
- Status register polling prevents premature operations
- Timeout protection on all operations

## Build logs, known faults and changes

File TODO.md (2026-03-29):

# Project TODO & Debugging Plan — rp2350 build / UF2 issues

Overview
--------
You reported that the firmware doesn't run on your `rp2350`. The build output shows linker errors referencing `GPIO_FAST_OP` being undefined, and you suspect either UF2 conversion or compilation/target mismatches. This TODO collects the investigation steps, prioritized fixes, and a concrete plan to make the firmware bare-metal (no direct SDK usage). Because you requested no direct SDK use, any small assembly wrappers or coprocessor helper functions we need must be copied into our own headers and kept inline/static to avoid external dependencies.

High-level goals
- Get a reproducible build for the rp2350 that links and produces a working `.elf` / `.bin` / `.uf2`.
- Replace or fix `GPIO_FAST_OP` so it compiles and links correctly for rp2350.
- Provide a minimal, copy-local set of assembler wrappers (copied from SDK style) in our own header(s) so we are bare-metal.
- Establish a reproducible diagnostic and UF2 creation workflow and document it here.

Current immediate failure (from build logs)
- Linker fails with undefined references to `GPIO_FAST_OP` coming from `src/main_board/low_level/gpio.c`.
- The file `src/main_board/low_level/gpio.c` *contains* a `void GPIO_FAST_OP(int op, int mask) { ... }` definition, but the linker still reports it as undefined.
- Possible causes: assembler / inline-asm incompatibility with target flags, function optimized away or made local, target mismatch (rp2040 vs rp2350), or code emitted differently than expected.

Top-level TODO (prioritized)
1. Diagnostics: confirm what object files actually contain for `gpio.c`.
   - Commands to run locally (repo root `D:\CodeProjects\drone-arm`):
     - `ninja -C build -v`  // verbose rebuild
     - `arm-none-eabi-nm build/src_main_board_low_level_gpio.c.o | grep GPIO_FAST_OP || true`
     - `arm-none-eabi-objdump -d build/src_main_board_low_level_gpio.c.o | sed -n '1,240p'`
     - `arm-none-eabi-readelf -s build/src_main_board_low_level_gpio.c.o | grep -i gpio || true`
     - Recompile `gpio.c` to assembly for review:
       - `arm-none-eabi-gcc -c -save-temps -Og -S -mcpu=cortex-m33 -mthumb -o /dev/null src/main_board/low_level/gpio.c`
   - Expected checks:
     - `nm` should show `GPIO_FAST_OP` as a defined symbol (type `T` or `t`).
     - `objdump` should show generated assembly for the function.
     - If `GPIO_FAST_OP` is not present, deduce why it was removed or not emitted.

2. Replace `GPIO_FAST_OP` with local, static inline coprocessor wrappers (copy of SDK wrappers)
   - Rationale:
     - Inline wrappers avoid external symbol emission.
     - We can't depend on SDK headers: copy minimal assembly wrappers into our own header(s).
     - Use `static inline` + `__asm__ volatile` to ensure proper emission and inlining.
   - Files to add (suggested):
     - `src/main_board/low_level/gpio_coproc_local.h` (exports `static inline` functions)
     - Update `src/main_board/low_level/gpio.c` to `#include "gpio_coproc_local.h"` and replace `GPIO_FAST_OP()` calls with small internal wrapper calls (or rename the function to `gpio_fast_op()` and implement as `static inline`).
   - Example mapping (we must adapt op -> wrapper):
     - op 0 -> `gpioc_lo_out_set(x)` or `gpioc_lo_out_put(x)` depending on semantics
     - op 1 -> `gpioc_lo_out_clr(x)`
     - op 2 -> `gpioc_lo_out_xor(x)`
     - op 4 -> `gpioc_lo_oe_set(x)` (output enable set)
     - op 5 -> `gpioc_lo_oe_clr(x)` (output enable clear)
     - For high bank (pins >= 32) use hi variants or direct SIO registers.

3. Rebuild and verify object/ELF
   - Rebuild: `ninja -C build`
   - Confirm `nm`/`readelf` shows no undefined references.
   - If undefined symbol persists, capture full link command and full linker error output.

4. UF2 conversion / flashing
   - Once ELF is valid, convert to UF2 using a local copy of conversion script or adhoc tool:
     - Preferred: repo-provided `elf2uf2` or `tools/elf2uf2/elf2uf2.py` (if present).
     - If none exists, craft a minimal UF2 creation flow (but prefer the tested tool).
   - Make sure the UF2 `target-family` GUID and metadata matches rp2350 bootloader expectation. Using rp2040 GUID will fail.
   - Flash with the standard drag/drop method or board-specific loader.

5. Document the final working flow & integrate into Meson/Ninja
   - Add the local header into the build include path.
   - Ensure `meson.build` references the new header (no linking to SDK).
   - Commit changes and update `TODO.md` with final steps.

Detailed debugging plan for `GPIO_FAST_OP`
- A. Inspect compiled object:
  - Run `arm-none-eabi-nm` on the `gpio.c.o` and check whether `GPIO_FAST_OP` is present and whether its symbol is local (`t`) or global (`T`).
  - If the function was compiled as `static` or inlined away, symbol type may differ — we must ensure it remains accessible from other compilation units if needed. But ideally we make it `static inline` and call local inline wrappers from each C file that needs it to avoid cross-object linkage.
- B. Inspect assembly emitted:
  - `objdump -d` the object file and locate the function body. Confirm correct encoding of `mcr` instruction lines.
- C. If assembly invalid or missing:
  - Replace the current `GPIO_FAST_OP` with a `static inline` set of named wrappers (see next section) and recompile.
- D. If linking still fails:
  - Capture full link command and check object list ordering; verify that `-Wl,--as-needed` or other flags are not stripping things unexpectedly.
  - Check for mismatched calling convention (unlikely in C) or symbol name mangling (shouldn’t happen with plain C).
- E. If coprocessor ops are invalid for cortex-m33:
  - The `mcr` instructions are RP2040-specific and intended for RP2040's coprocessor usage. If the rp2350 core does not support these exact `mcr` encodings, the assembler will reject them or encode them differently — you may need to implement direct SIO register writes for the rp2350 chip (write to `SIO_BASE + offset`), or use the rp2350-provided fastest mechanism.
  - Confirm the `mcr` instruction semantics for rp2350; if not supported, use memory-mapped SIO register writes.

Concrete code approach (no SDK imports — copy only the minimal wrappers)
- Create `src/main_board/low_level/gpio_coproc_local.h` that defines a small set of `static inline` functions (copy/paste of the SDK wrappers, but self-contained). Example recommended contents (adapted for our repo; ensure the path included by `gpio.c`):

Contents suggestion for `src/main_board/low_level/gpio_coproc_local.h`:
- Provide a small macro / inline-asm helper, and define low/high bank functions as `static inline`.
- Use names prefixed to avoid collision: `local_gpioc_lo_out_set`, etc.
- Keep functions `static inline` so they are not emitted as linkable symbols.

Example (to copy into the new header):
- Use `__asm__ volatile ("mcr p0, #<opc>, %0, c<0>, c<0>" : : "r" (x));` form for low out ops.
- Use `c4` for OE ops as seen in existing SDK wrappers, and `c1` for hi bank variants (see SDK mapping).
- Document these wrappers carefully (source attribution: derived from SDK style; adapted for local use).

(Important note: exact `mcr` operands and `#` immediates must match the SDK wrappers you observed. The header below is an example you should include exactly in the file tree as `src/main_board/low_level/gpio_coproc_local.h`.)

Suggested header skeleton (text form to be saved as the new header):
- `#ifndef MAIN_BOARD_LOW_LEVEL_GPIO_COPROC_LOCAL_H`
- `#define MAIN_BOARD_LOW_LEVEL_GPIO_COPROC_LOCAL_H`
- `static inline void local_gpioc_lo_out_put(uint32_t x) { __asm__ volatile ("mcr p0, #0, %0, c0, c0" : : "r"(x)); }`
- `...` (similar wrappers for `out_xor`, `out_set`, `out_clr`, `hi_*` variants, `lo_oe_*` and `hi_oe_*`) 
- `#endif`

(You will add this file; then change `gpio.c` calls from `GPIO_FAST_OP(op, mask)` to a small local inline `gpio_fast_op(op, mask)` that dispatches to the local_gpioc_* functions in `gpio_coproc_local.h`.)

Example `gpio.c` change (conceptual)
- At top: `#include "gpio_coproc_local.h"`
- Replace:
  - `void GPIO_FAST_OP(int op, int mask) { switch(op) { case 0: __asm__ volatile ("mcr ..."); ... } }`
- With:
  - `static inline void local_gpio_fast_op(int op, int mask) { switch (op) { case 0: local_gpioc_lo_out_set(mask); break; ... } }`
  - Replace all callers `GPIO_FAST_OP(...)` with `local_gpio_fast_op(...)` or call the appropriate low/high wrapper inline directly from callsites.

Why this approach avoids the current link error
- `static inline` wrappers are inlined at call sites; no external symbol is emitted and thus nothing to be resolved by the linker.
- Copying only the tiny wrappers keeps the codebase bare-metal and independent of SDK headers while retaining the same inline assembly patterns that were used in the SDK.
- If the `mcr` op is incompatible with the target CPU/assembler, the asm will fail at compile/assemble time; at that stage we'll know the instruction set mismatch and can switch to explicit SIO register writes.

If the coprocessor assembly is not supported for rp2350
- Fallback: implement direct SIO register writes. The repo already includes `addressmap.h` and `structs/sio.h` with offsets; use `REG32_WRITE(SIO_BASE + SIO_GPIO_OUT_SET_OFFSET, mask)` style writes for the low/high banks instead of coproc ops.
- Using memory mapped writes is slightly slower but fully portable across cores that expose the SIO block.

Detailed test & verification steps
1. Implement the header + `gpio.c` changes (local wrappers).
2. Build: `ninja -C build`.
3. If build succeeds, verify `nm`/`readelf` that no undefined `GPIO_FAST_OP` remains:
   - `arm-none-eabi-readelf -s build/firmware_main_board.elf | grep -i GPIO_FAST_OP || true`
4. Run tests (if available) or flash on board:
   - Convert ELF -> UF2 (local tool): `python3 tools/elf2uf2/elf2uf2.py firmware_main_board.elf firmware_main_board.uf2` (adjust path/tool as needed)
   - Drag-drop `.uf2` to the board if it presents as mass storage, or flash via `picotool`/`openocd` as appropriate for rp2350.
5. If board does not boot: collect serial logs, link map, and `dmesg` on host to see mount/boot messages.

Failure escalation
- If assembler rejects `mcr` opcodes:
  - Capture the assembler error and the exact compile args; we will adapt the inline asm to valid instructions or use memory-mapped SIO registers.
- If `GPIO_FAST_OP` still reported as undefined after replacement:
  - Re-check for stale object files, cleaning `build/` and a full rebuild: `ninja -C build -t clean` or remove `build/` and re-run Meson/Ninja configure/build.
- If UF2 fails to flash or boot:
  - Check UF2 `target-family` GUID; create UF2 with correct GUID for rp2350. If unknown, check board documentation, or test with the `.bin` via `picotool load` or `openocd` to confirm ELF is valid before uf2 conversion.

Files to create/update (concrete)
- Create: `src/main_board/low_level/gpio_coproc_local.h` (copy minimal wrappers here)
- Update: `src/main_board/low_level/gpio.c`
  - `#include "gpio_coproc_local.h"`
  - Replace `GPIO_FAST_OP` with `static inline` local wrapper dispatching to `local_gpioc_*` functions
- Update Meson include paths if necessary (to include `src/main_board/low_level`).
- Add unit/build debug target that compiles `gpio.c` to assembly for quick checks.

Acceptance criteria
- Clean build: `ninja -C build` completes with zero link errors.
- `arm-none-eabi-nm` on the object files shows no undefined `GPIO_FAST_OP`.
- Board boots the new firmware and basic GPIO operations work (toggle LED or read input).
- UF2 produced with correct metadata flashes successfully and board runs firmware.

Next immediate action (I will do this when you confirm)
- Implement the local header `gpio_coproc_local.h` and change `gpio.c` to use the inline wrappers and re-run the build.
- If you want me to proceed now, confirm and I will start by creating `src/main_board/low_level/gpio_coproc_local.h` and updating `gpio.c` to use it. If you prefer to run the diagnostic commands first and paste outputs, I’ll analyze them before making edits.

Notes / caveats
- The `mcr` coprocessor assembly sequences are architecture-specific. If rp2350's Cortex-M33 core differs from the RP2040 approach, memory mapped SIO writes will be the fallback.
- Because you requested not to use SDK headers directly, I will only copy the minimal inline assembly wrappers into our local header — no other SDK code will be referenced.
- Keep a short audit comment in the local header that notes the code was adapted (source: SDK-style wrapper), and state which SDK version you copied from for traceability.

Timeline estimate
- Diagnostics & initial header + small edits: 30–90 minutes.
- Rebuild + debug: another 15–60 minutes depending on issues found.
- UF2 conversion and flash verification: 15–45 minutes.

End of TODO. Make sure to commit changes to the repo and push a branch like `fix/gpio-fast-op-local` for traceability.

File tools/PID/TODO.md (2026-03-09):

Here is the project: **Drone Pitch Autopilot — PID Design + MDO-Based Gain Optimization**.

The two libraries don't just coexist here — they *integrate*. OpenMDAO drives the optimizer, and the `control` library lives *inside* an OpenMDAO component as the physics evaluator. This mirrors exactly how RTX/Boeing/NASA use OpenMDAO: a discipline analysis tool (here, control theory) is wrapped as a component, and a trade study optimizer sits on top.

***

## The Concept

Model a quadrotor's linearized pitch dynamics as a second-order transfer function, design a PID controller on top of it, then use OpenMDAO to *optimally tune the PID gains* subject to stability margin constraints.

**Why this is realistic:** Linearized pitch dynamics of a drone in hover can be written as:

$$
G(s) = \frac{1}{I_{xx} s^2 + b_{damp} \cdot s}
$$

where $I_{xx}$ is the moment of inertia about the pitch axis and $b_{damp}$ is aerodynamic damping. A PID controller in the Laplace domain is:

$$
C(s) = K_p + \frac{K_i}{s} + K_d s = \frac{K_d s^2 + K_p s + K_i}{s}
$$

The open-loop plant is $L(s) = C(s) \cdot G(s)$, and the closed-loop response is $T(s) = \frac{L(s)}{1 + L(s)}$.

***

## File Structure

```
PID/
├── drone_model.py       # TF definition + stability analysis using control lib
├── pid_component.py     # OpenMDAO ExplicitComponent wrapping control library
├── optimization.py      # OpenMDAO Problem setup, optimizer, constraints
├── plots.py             # Bode, Nyquist, pole-zero, step response figures
├── main.py              # Orchestrator: analyze → optimize → compare
└── TODO.md              # This file you're reading now
```

***

## Part 1 — `control` Library (drone_model.py + plots.py)

This is the pure control-systems showcase.[^1][^2]

- **Transfer function:** `control.tf([^1], [Ixx, b, 0])` — the denominator `s(Ixx·s + b)` captures the double-integrator-like pitch physics
- **PID as a TF:** `control.tf([Kd, Kp, Ki], [1, 0])` — numerator is the PID polynomial, denominator is `s`
- **Closed-loop:** `control.feedback(C * G, 1)` — unity feedback
- **Bode plot:** `control.bode_plot(open_loop_tf)` — magnitude + phase vs. frequency; you read off gain/phase margins visually[^2]
- **Nyquist diagram:** `control.nyquist_plot(open_loop_tf)` — encirclements of -1 tell you Nyquist stability criterion[^3]
- **Pole-zero map:** `control.pzmap(closed_loop_tf)` — visualize where roots land in the complex plane
- **Step response:** `control.step_response(closed_loop_tf)` — read off settling time and overshoot
- **Margins:** `control.stability_margins(open_loop_tf)` — returns `(gm, pm, wg, wp)` numerically

This alone covers every bullet in your requirement list.

***

## Part 2 — OpenMDAO (pid_component.py + optimization.py)

Wrap the control-library analysis as an OpenMDAO `ExplicitComponent`.[^4][^5]

```
class PIDPerformanceComp(om.ExplicitComponent):
    setup():
        add_input:  Kp, Ki, Kd
        add_output: settling_time, overshoot_pct, gain_margin_dB, phase_margin_deg
        declare_partials('*', '*', method='fd')   # finite-diff, no need for analytic grad

    compute(inputs, outputs):
        # Build TFs using control library
        # Run step_response → extract settling_time, overshoot
        # Run stability_margins → extract gm, pm
        # Populate outputs dict
```

Then the optimization problem:

| MDO Element | Value |
| :-- | :-- |
| **Design variables** | `Kp ∈ [0.1, 50]`, `Ki ∈ [0, 20]`, `Kd ∈ [0, 10]` |
| **Objective** | minimize `settling_time + 0.05 × overshoot_pct` |
| **Constraint 1** | `gain_margin_dB ≥ 6 dB` (robustness floor) |
| **Constraint 2** | `phase_margin_deg ≥ 45°` (standard aerospace requirement) |
| **Optimizer** | `ScipyOptimizeDriver` with `SLSQP` |

***

## What the Final Output Shows

**Before optimization** (hand-tuned initial gains, e.g. Kp=5, Ki=1, Kd=0.5):

- Bode plot with gain/phase margins marked
- Nyquist with -1 point reference
- Step response showing sluggish or oscillatory behavior

**After OpenMDAO optimization:**

- Same four plots, but now settling time is minimized and margins are satisfied
- A printed table comparing before/after: gains, settling time, overshoot, GM, PM

This gives you a **side-by-side story** — the `control` library provides the domain physics, and OpenMDAO provides the structured optimizer that no manual Ziegler-Nichols tuning can match.

***

## Time Estimate

| Task | Time |
| :-- | :-- |
| `drone_model.py` + `plots.py` | ~30 min |
| `pid_component.py` | ~25 min |
| `optimization.py` + `main.py` | ~20 min |
| Debugging + plot formatting | ~15 min |
| **Total** | **~90 min** |

The biggest gotcha to watch for: `control.stability_margins()` can return `inf` for gain margin if the phase never crosses −180°, so add a clamp or catch on the output before passing into OpenMDAO. Also use `method='fd'` (finite difference) for partials — trying to compute analytic derivatives through the `control` library is not worth the effort for a 1-2 hour project.
<span style="display:none">[^10][^11][^12][^13][^14][^15][^6][^7][^8][^9]</span>

<div align="center">⁂</div>

[^1]: https://python-control.readthedocs.io/en/latest/generated/control.TransferFunction.html

[^2]: https://python-control.readthedocs.io/en/latest/generated/control.bode_plot.html

[^3]: https://www.youtube.com/watch?v=ak3_-wRDIMQ

[^4]: https://openmdao.org/newdocs/versions/latest/features/core_features/working_with_components/explicit_component.html

[^5]: https://modopt.readthedocs.io/en/latest/src/_temp/examples/ex_5quartic_opt_openmdao.html

[^7]: https://openmdao.org/newdocs/versions/latest/_srcdocs/packages/core/explicitcomponent.html

[^8]: https://www.youtube.com/watch?v=SzHOShB6d3E

[^9]: https://snyk.io/advisor/python/openmdao/functions/openmdao.api.ExplicitComponent

[^10]: https://www.youtube.com/watch?v=J-UbVnhsyJ0

[^11]: https://ntrs.nasa.gov/api/citations/20180004467/downloads/20180004467.pdf

[^13]: https://www.youtube.com/watch?v=yHlC1pG_Dmw

[^14]: https://github.com/python-control/python-control/blob/main/examples/bode-and-nyquist-plots.ipynb

[^15]: https://openmdao.github.io/PracticalMDO/Notebooks/Optimization/debugging_your_optimizations.html

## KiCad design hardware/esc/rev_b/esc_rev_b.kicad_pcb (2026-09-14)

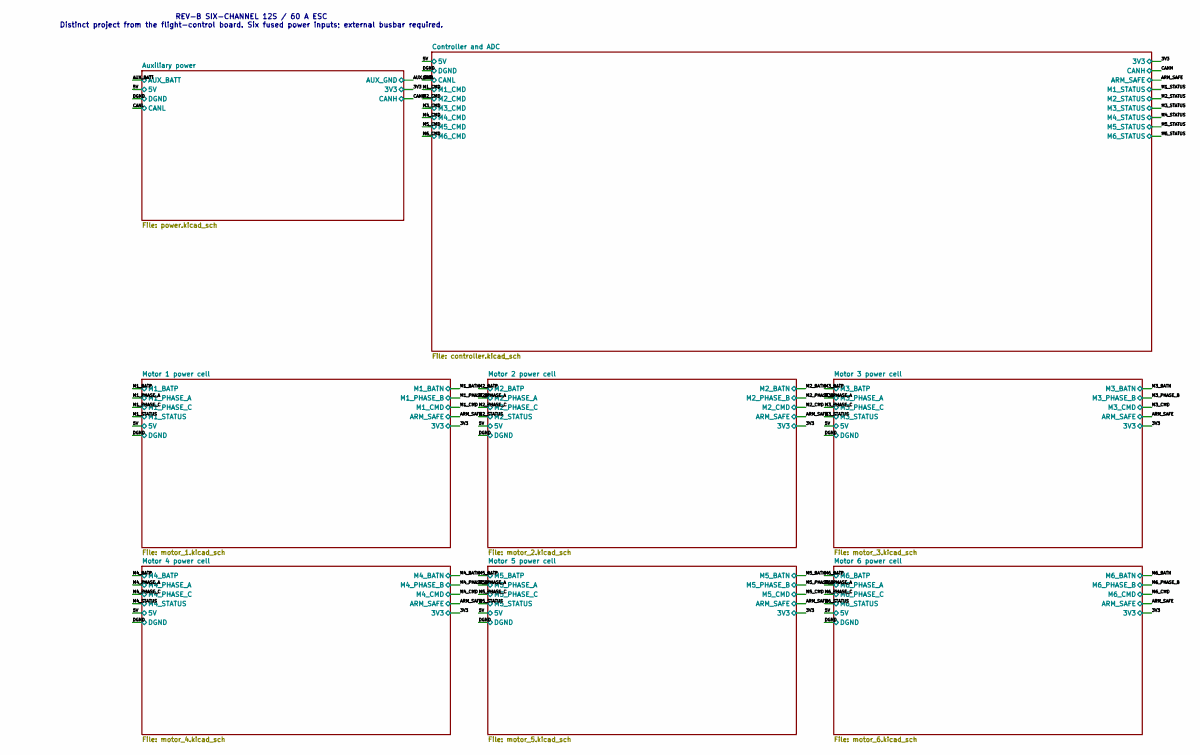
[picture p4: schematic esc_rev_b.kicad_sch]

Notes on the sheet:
REV-B SIX-CHANNEL 12S / 60 A ESC Distinct project from the flight-control board. Six fused power inputs; external busbar required.

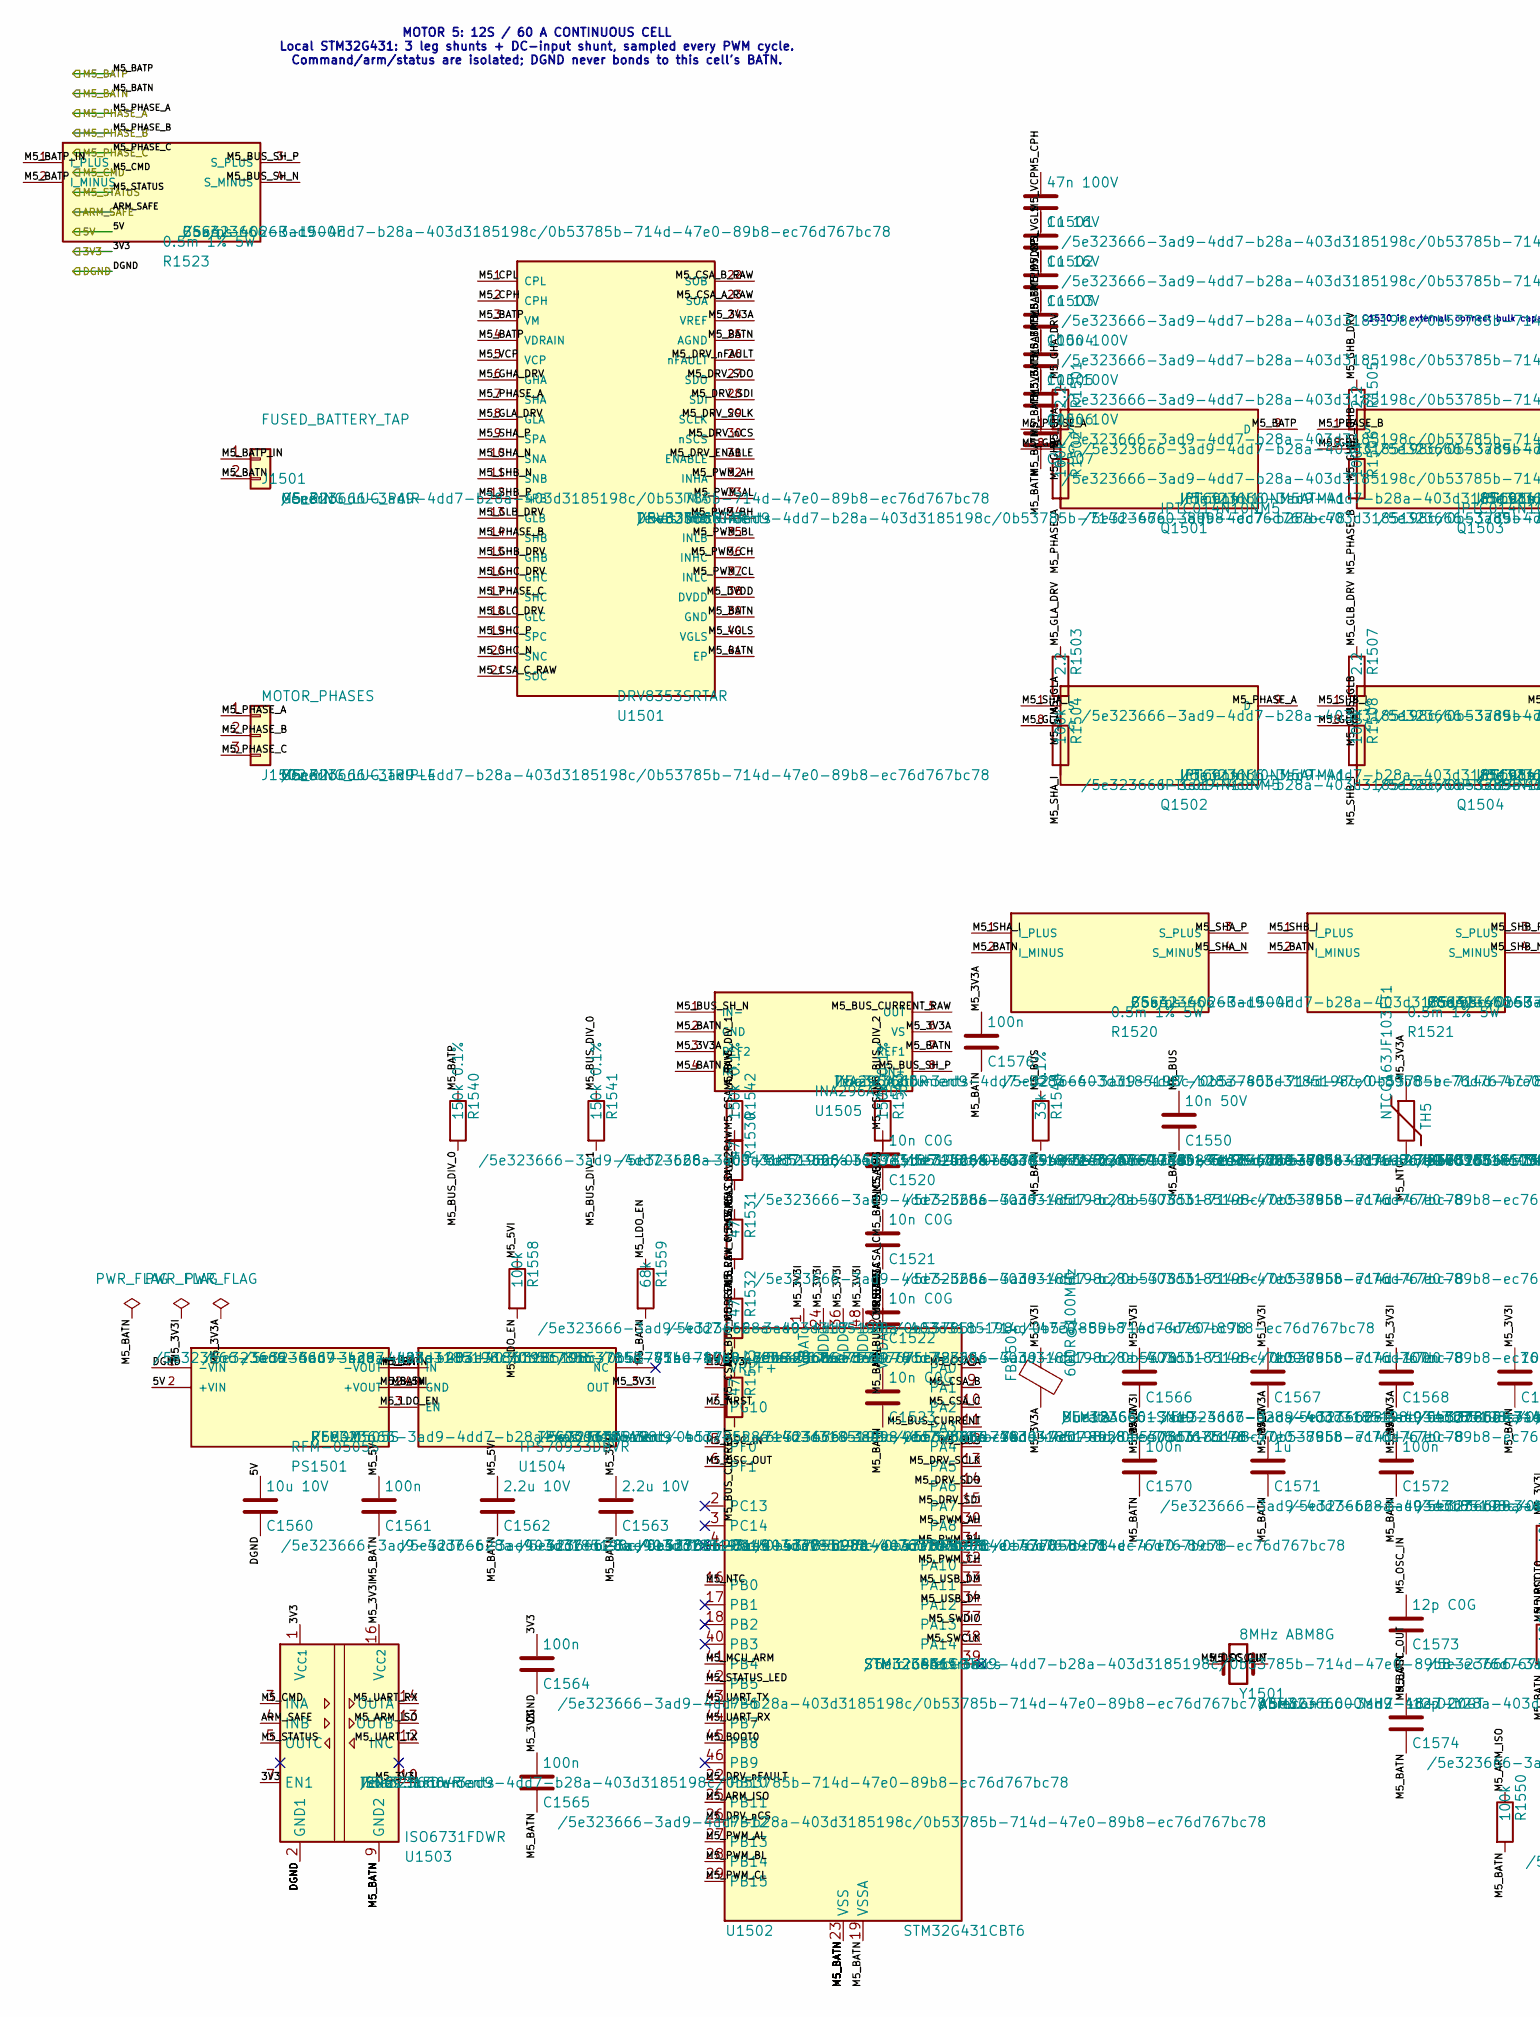
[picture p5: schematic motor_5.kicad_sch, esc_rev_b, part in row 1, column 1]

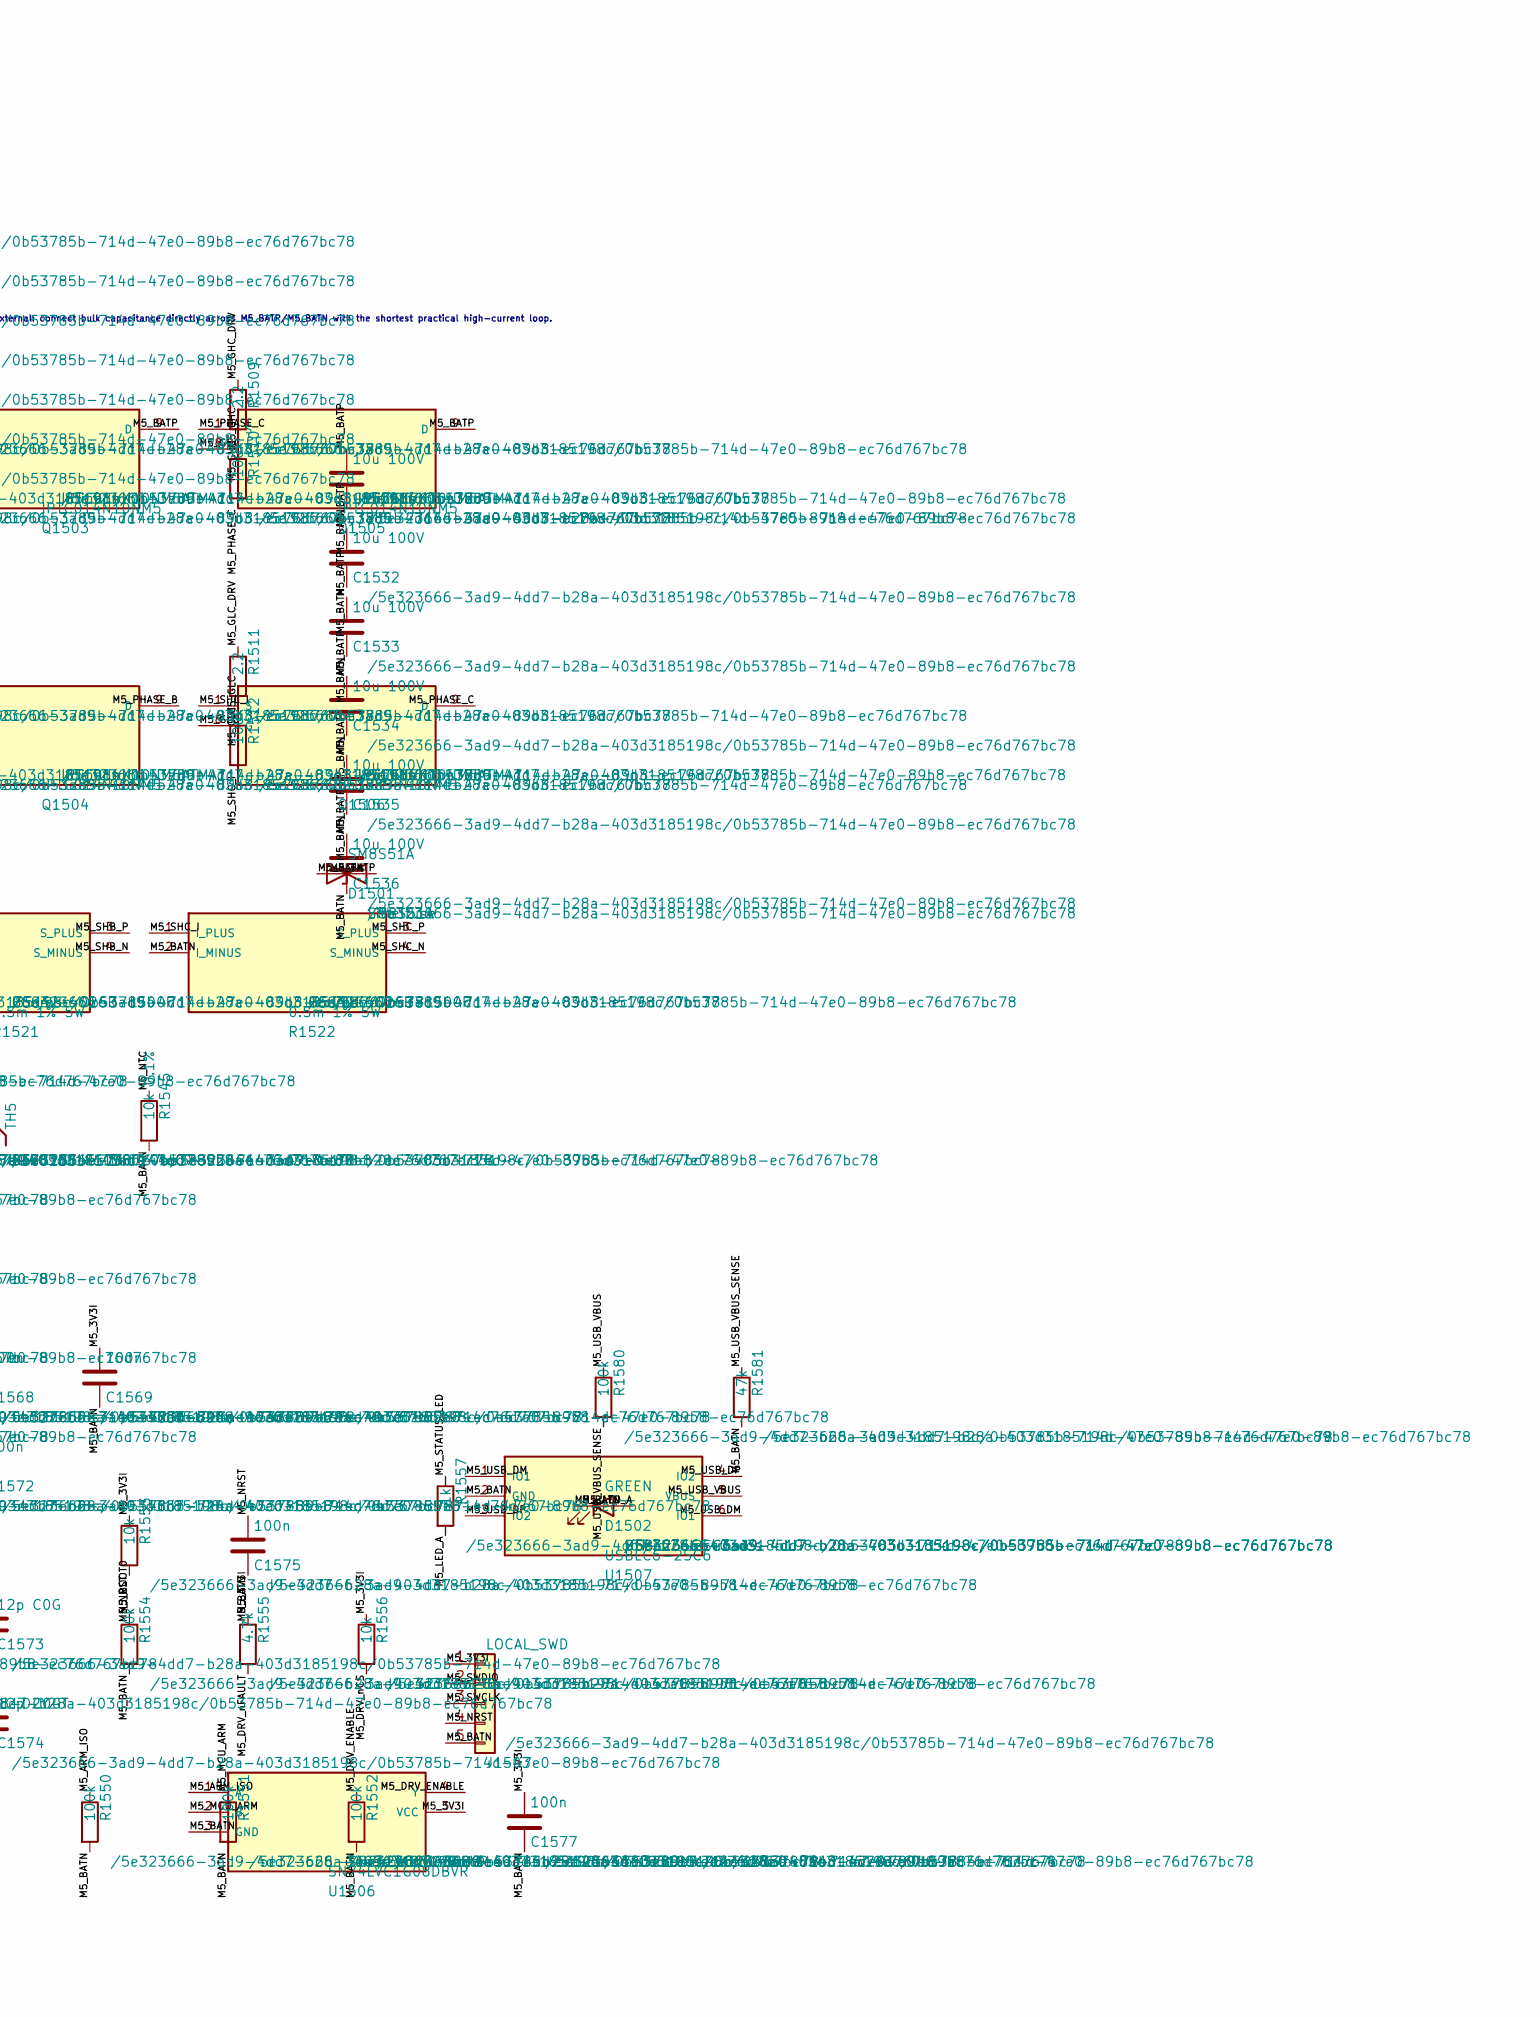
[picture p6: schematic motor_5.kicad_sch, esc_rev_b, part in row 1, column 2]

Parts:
C1501: 47n 100V; C_0603_1608Metric
C1502, C1503: 1u 16V; C_0603_1608Metric
C1504: 1u 10V; C_0603_1608Metric
C1505: 100n 100V; C_0603_1608Metric
C1506, C1531, C1532, C1533, C1534, C1535, C1536: 10u 100V; C_1210_3225Metric
C1507: 100n 10V; C_0603_1608Metric
C1520, C1521, C1522, C1523: 10n C0G; C_0603_1608Metric
C1550: 10n 50V; C_0603_1608Metric
C1560: 10u 10V; C_0805_2012Metric
C1561, C1564, C1565, C1575, C1576, C1577: 100n; C_0603_1608Metric
C1562, C1563: 2.2u 10V; C_0603_1608Metric
C1566: 4.7u; C_0603_1608Metric
C1567, C1568, C1569, C1570, C1572: 100n; C_0402_1005Metric
C1571: 1u; C_0603_1608Metric
C1573, C1574: 12p C0G; C_0402_1005Metric
D1501: SM8S51A; DO-218AB_SM8S; MPN SM8S51A
D1502: GREEN; LED_0603_1608Metric
FB1501: 600R@100MHz; L_0603_1608Metric; MPN BLM18AG601SN1D
J1501: FUSED_BATTERY_TAP; POWER_LUG_M5_2P_P20; MPN M5_RING_LUG_PAIR
J1502: MOTOR_PHASES; POWER_LUG_M5_3P_P20; MPN M5_RING_LUG_TRIPLE
J1503: LOCAL_SWD; PinHeader_1x05_P1.27mm_Vertical
PS1501: RFM-0505S; RFM_SIP4_11.5x6_P2.54; MPN RFM-0505S
Q1501, Q1502, Q1503, Q1504, Q1505, Q1506: IPTC014N10NM5; PG-HDSOP-16_TOLT_IPTC; MPN IPTC014N10NM5ATMA1
R1501, R1503, R1505, R1507, R1509, R1511: 2.2; R_0603_1608Metric
R1502, R1504, R1506, R1508, R1510, R1512, R1550, R1551, R1552, R1554, R1558, R1580: 100k; R_0603_1608Metric
R1520, R1521, R1522, R1523: 0.5m 1% 5W; CSS4J-4026_Kelvin; MPN CSS4J-4026R-L500F
R1530, R1531, R1532, R1533: 47; R_0603_1608Metric
R1540, R1541, R1542, R1543: 150k 0.1%; R_1206_3216Metric
R1544: 33k 0.1%; R_0603_1608Metric
R1545: 10k 0.1%; R_0603_1608Metric
R1553, R1556: 10k; R_0603_1608Metric
R1555: 4.7k; R_0603_1608Metric
R1557: 1k; R_0603_1608Metric
R1559: 68k; R_0603_1608Metric
R1581: 47k; R_0603_1608Metric
TH5: NTCG163JF103FT1; R_0603_1608Metric; MPN NTCG163JF103FT1
U1501: DRV8353SRTAR; WQFN-40-EP_6x6_P0.5; MPN DRV8353SRTAR
U1502: STM32G431CBT6; LQFP-48_7x7mm_P0.5mm; MPN STM32G431CBT6
U1503: ISO6731FDWR; SOIC-16W_7.5x10.3mm_P1.27mm; MPN ISO6731FDWR
U1504: TPS70933DBVR; SOT-23-5; MPN TPS70933DBVR
U1505: INA296A2IDR; SOIC-8_3.9x4.9mm_P1.27mm; MPN INA296A2IDR
U1506: SN74LVC1G08DBVR; SOT-23-5; MPN SN74LVC1G08DBVR
U1507: USBLC6-2SC6; SOT-23-6; MPN USBLC6-2SC6
Y1501: 8MHz ABM8G; Crystal_SMD_3225-4Pin_3.2x2.5mm; MPN ABM8G-8.000MHZ-18-D2Y-T

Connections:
/3V3: C1564.1, U1503.1 (V_{CC1}), U1503.7 (EN1); also elsewhere on the board
/5V: C1560.1, PS1501.2 (+VIN); also elsewhere on the board
/ARM_SAFE: U1503.4 (INB); also elsewhere on the board
/DGND: C1560.2, C1564.2, PS1501.1 (-VIN), U1503.2 (GND1), U1503.8 (GND1); also elsewhere on the board
/M5_BATN: C1503.2, C1504.2, C1505.2, C1506.2, C1507.2, C1520.2, C1521.2, C1522.2, C1523.2, C1531.2, C1532.2, C1533.2, C1534.2, C1535.2, C1536.2, C1550.2, C1561.2, C1562.2, C1563.2, C1565.2, C1566.2, C1567.2, C1568.2, C1569.2, C1570.2, C1571.2, C1572.2, C1573.2, C1574.2, C1575.2, C1576.2, C1577.2, D1501.1 (A1), D1502.1 (K), J1501.2, J1503.5, PS1501.3 (-VOUT), R1520.2 (I_MINUS), R1521.2 (I_MINUS), R1522.2 (I_MINUS), R1544.2, R1545.2, R1550.2, R1551.2, R1552.2, R1554.2, R1559.2, R1581.2, U1501.25 (AGND), U1501.39 (GND), U1501.41 (EP), U1502.19 (VSSA), U1502.23 (VSS), U1502.35 (VSS), U1502.47 (VSS), U1503.9 (GND2), U1503.15 (GND2), U1504.2 (GND), U1505.2 (GND), U1505.4 (NC), U1505.7 (REF1), U1506.3 (GND), U1507.2 (GND); also elsewhere on the board
/M5_BATP: C1502.2, C1505.1, C1506.1, C1531.1, C1532.1, C1533.1, C1534.1, C1535.1, C1536.1, D1501.2 (A2), Q1501.9 (D), Q1503.9 (D), Q1505.9 (D), R1523.2 (I_MINUS), R1540.1, U1501.3 (VM), U1501.4 (VDRAIN); also elsewhere on the board
/M5_CMD: U1503.3 (INA); also elsewhere on the board
/M5_PHASE_A: J1502.1, Q1501.1 (S), Q1502.9 (D), R1502.2, U1501.7 (SHA)
/M5_PHASE_B: J1502.2, Q1503.1 (S), Q1504.9 (D), R1506.2, U1501.14 (SHB)
/M5_PHASE_C: J1502.3, Q1505.1 (S), Q1506.9 (D), R1510.2, U1501.17 (SHC)
/M5_STATUS: U1503.5 (OUTC); also elsewhere on the board
/Motor 5 power cell/M5_3V3A: C1507.1, C1571.1, C1572.1, C1576.1, FB1501.2, TH5.1, U1501.24 (VREF), U1502.20 (VREF+), U1502.21 (VDDA), U1505.3 (REF2), U1505.6 (VS)
/Motor 5 power cell/M5_3V3I: C1563.1, C1565.1, C1566.1, C1567.1, C1568.1, C1569.1, C1570.1, C1577.1, FB1501.1, J1503.1, R1553.1, R1555.1, R1556.1, U1502.1 (VBAT), U1502.24 (VDD), U1502.36 (VDD), U1502.48 (VDD), U1503.10 (EN2), U1503.16 (V_{CC2}), U1504.5 (OUT), U1506.5 (VCC)
/Motor 5 power cell/M5_5VI: C1561.1, C1562.1, PS1501.4 (+VOUT), R1558.1, U1504.1 (IN)
/Motor 5 power cell/M5_ARM_ISO: R1550.1, U1502.25 (PB11), U1503.13 (OUTB), U1506.1 (A)
/Motor 5 power cell/M5_BATP_IN: J1501.1, R1523.1 (I_PLUS)
/Motor 5 power cell/M5_BOOT0: R1554.1, U1502.45 (PB8)
/Motor 5 power cell/M5_BUS: C1550.1, R1543.2, R1544.1, U1502.12 (PA4)
/Motor 5 power cell/M5_BUS_CURRENT: C1523.1, R1533.2, U1502.11 (PA3)
/Motor 5 power cell/M5_BUS_CURRENT_RAW: R1533.1, U1505.5 (OUT)
/Motor 5 power cell/M5_BUS_DIV_0: R1540.2, R1541.1
/Motor 5 power cell/M5_BUS_DIV_1: R1541.2, R1542.1
/Motor 5 power cell/M5_BUS_DIV_2: R1542.2, R1543.1
/Motor 5 power cell/M5_BUS_SH_N: R1523.4 (S_MINUS), U1505.1 (IN-)
/Motor 5 power cell/M5_BUS_SH_P: R1523.3 (S_PLUS), U1505.8 (IN+)
/Motor 5 power cell/M5_CPH: C1501.1, U1501.2 (CPH)
/Motor 5 power cell/M5_CPL: C1501.2, U1501.1 (CPL)
/Motor 5 power cell/M5_CSA_A: C1520.1, R1530.2, U1502.8 (PA0)
/Motor 5 power cell/M5_CSA_A_RAW: R1530.1, U1501.23 (SOA)
/Motor 5 power cell/M5_CSA_B: C1521.1, R1531.2, U1502.9 (PA1)
/Motor 5 power cell/M5_CSA_B_RAW: R1531.1, U1501.22 (SOB)
/Motor 5 power cell/M5_CSA_C: C1522.1, R1532.2, U1502.10 (PA2)
/Motor 5 power cell/M5_CSA_C_RAW: R1532.1, U1501.21 (SOC)
/Motor 5 power cell/M5_DRV_ENABLE: R1552.1, U1501.31 (ENABLE), U1506.4 (Y)
/Motor 5 power cell/M5_DRV_SCLK: U1501.29 (SCLK), U1502.13 (PA5)
/Motor 5 power cell/M5_DRV_SDI: U1501.28 (SDI), U1502.15 (PA7)
/Motor 5 power cell/M5_DRV_SDO: U1501.27 (SDO), U1502.14 (PA6)
/Motor 5 power cell/M5_DRV_nCS: R1556.2, U1501.30 (nSCS), U1502.26 (PB12)
/Motor 5 power cell/M5_DRV_nFAULT: R1555.2, U1501.26 (nFAULT), U1502.22 (PB10)
/Motor 5 power cell/M5_DVDD: C1504.1, U1501.38 (DVDD)
/Motor 5 power cell/M5_GHA: Q1501.8 (G), R1501.2, R1502.1
/Motor 5 power cell/M5_GHA_DRV: R1501.1, U1501.6 (GHA)
/Motor 5 power cell/M5_GHB: Q1503.8 (G), R1505.2, R1506.1
/Motor 5 power cell/M5_GHB_DRV: R1505.1, U1501.15 (GHB)
/Motor 5 power cell/M5_GHC: Q1505.8 (G), R1509.2, R1510.1
/Motor 5 power cell/M5_GHC_DRV: R1509.1, U1501.16 (GHC)
/Motor 5 power cell/M5_GLA: Q1502.8 (G), R1503.2, R1504.1
/Motor 5 power cell/M5_GLA_DRV: R1503.1, U1501.8 (GLA)
/Motor 5 power cell/M5_GLB: Q1504.8 (G), R1507.2, R1508.1
/Motor 5 power cell/M5_GLB_DRV: R1507.1, U1501.13 (GLB)
/Motor 5 power cell/M5_GLC: Q1506.8 (G), R1511.2, R1512.1
/Motor 5 power cell/M5_GLC_DRV: R1511.1, U1501.18 (GLC)
/Motor 5 power cell/M5_LDO_EN: R1558.2, R1559.1, U1504.3 (EN)
/Motor 5 power cell/M5_LED_A: D1502.2 (A), R1557.2
/Motor 5 power cell/M5_MCU_ARM: R1551.1, U1502.41 (PB4), U1506.2 (B)
/Motor 5 power cell/M5_NRST: C1575.1, J1503.4, R1553.2, U1502.7 (PG10)
/Motor 5 power cell/M5_NTC: R1545.1, TH5.2, U1502.16 (PB0)
/Motor 5 power cell/M5_OSC_IN: C1573.1, U1502.5 (PF0), Y1501.1
/Motor 5 power cell/M5_OSC_OUT: C1574.1, U1502.6 (PF1), Y1501.2
/Motor 5 power cell/M5_PWM_AH: U1501.32 (INHA), U1502.30 (PA8)
/Motor 5 power cell/M5_PWM_AL: U1501.33 (INLA), U1502.27 (PB13)
/Motor 5 power cell/M5_PWM_BH: U1501.34 (INHB), U1502.31 (PA9)
/Motor 5 power cell/M5_PWM_BL: U1501.35 (INLB), U1502.28 (PB14)
/Motor 5 power cell/M5_PWM_CH: U1501.36 (INHC), U1502.32 (PA10)
/Motor 5 power cell/M5_PWM_CL: U1501.37 (INLC), U1502.29 (PB15)
/Motor 5 power cell/M5_SHA_I: Q1502.1 (S), R1504.2, R1520.1 (I_PLUS)
/Motor 5 power cell/M5_SHA_N: R1520.4 (S_MINUS), U1501.10 (SNA)
/Motor 5 power cell/M5_SHA_P: R1520.3 (S_PLUS), U1501.9 (SPA)
/Motor 5 power cell/M5_SHB_I: Q1504.1 (S), R1508.2, R1521.1 (I_PLUS)
/Motor 5 power cell/M5_SHB_N: R1521.4 (S_MINUS), U1501.11 (SNB)
/Motor 5 power cell/M5_SHB_P: R1521.3 (S_PLUS), U1501.12 (SPB)
/Motor 5 power cell/M5_SHC_I: Q1506.1 (S), R1512.2, R1522.1 (I_PLUS)
/Motor 5 power cell/M5_SHC_N: R1522.4 (S_MINUS), U1501.20 (SNC)
/Motor 5 power cell/M5_SHC_P: R1522.3 (S_PLUS), U1501.19 (SPC)
/Motor 5 power cell/M5_STATUS_LED: R1557.1, U1502.42 (PB5)
/Motor 5 power cell/M5_SWCLK: J1503.3, U1502.38 (PA14)
/Motor 5 power cell/M5_SWDIO: J1503.2, U1502.37 (PA13)
/Motor 5 power cell/M5_UART_RX: U1502.44 (PB7), U1503.14 (OUTA)
/Motor 5 power cell/M5_UART_TX: U1502.43 (PB6), U1503.12 (INC)
/Motor 5 power cell/M5_USB_DM: U1502.33 (PA11), U1507.1 (IO1), U1507.6 (IO1)
/Motor 5 power cell/M5_USB_DP: U1502.34 (PA12), U1507.3 (IO2), U1507.4 (IO2)
/Motor 5 power cell/M5_USB_VBUS: R1580.1, U1507.5 (VBUS)
/Motor 5 power cell/M5_USB_VBUS_SENSE: R1580.2, R1581.1
/Motor 5 power cell/M5_VCP: C1502.1, U1501.5 (VCP)
/Motor 5 power cell/M5_VGLS: C1503.1, U1501.40 (VGLS)

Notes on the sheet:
MOTOR 5: 12S / 60 A CONTINUOUS CELL Local STM32G431: 3 leg shunts + DC-input shunt, sampled every PWM cycle. Command/arm/status are isolated; DGND never bonds to this cell's BATN.
C1530 is external: connect bulk capacitance directly across M5_BATP/M5_BATN with the shortest practical high-current loop.

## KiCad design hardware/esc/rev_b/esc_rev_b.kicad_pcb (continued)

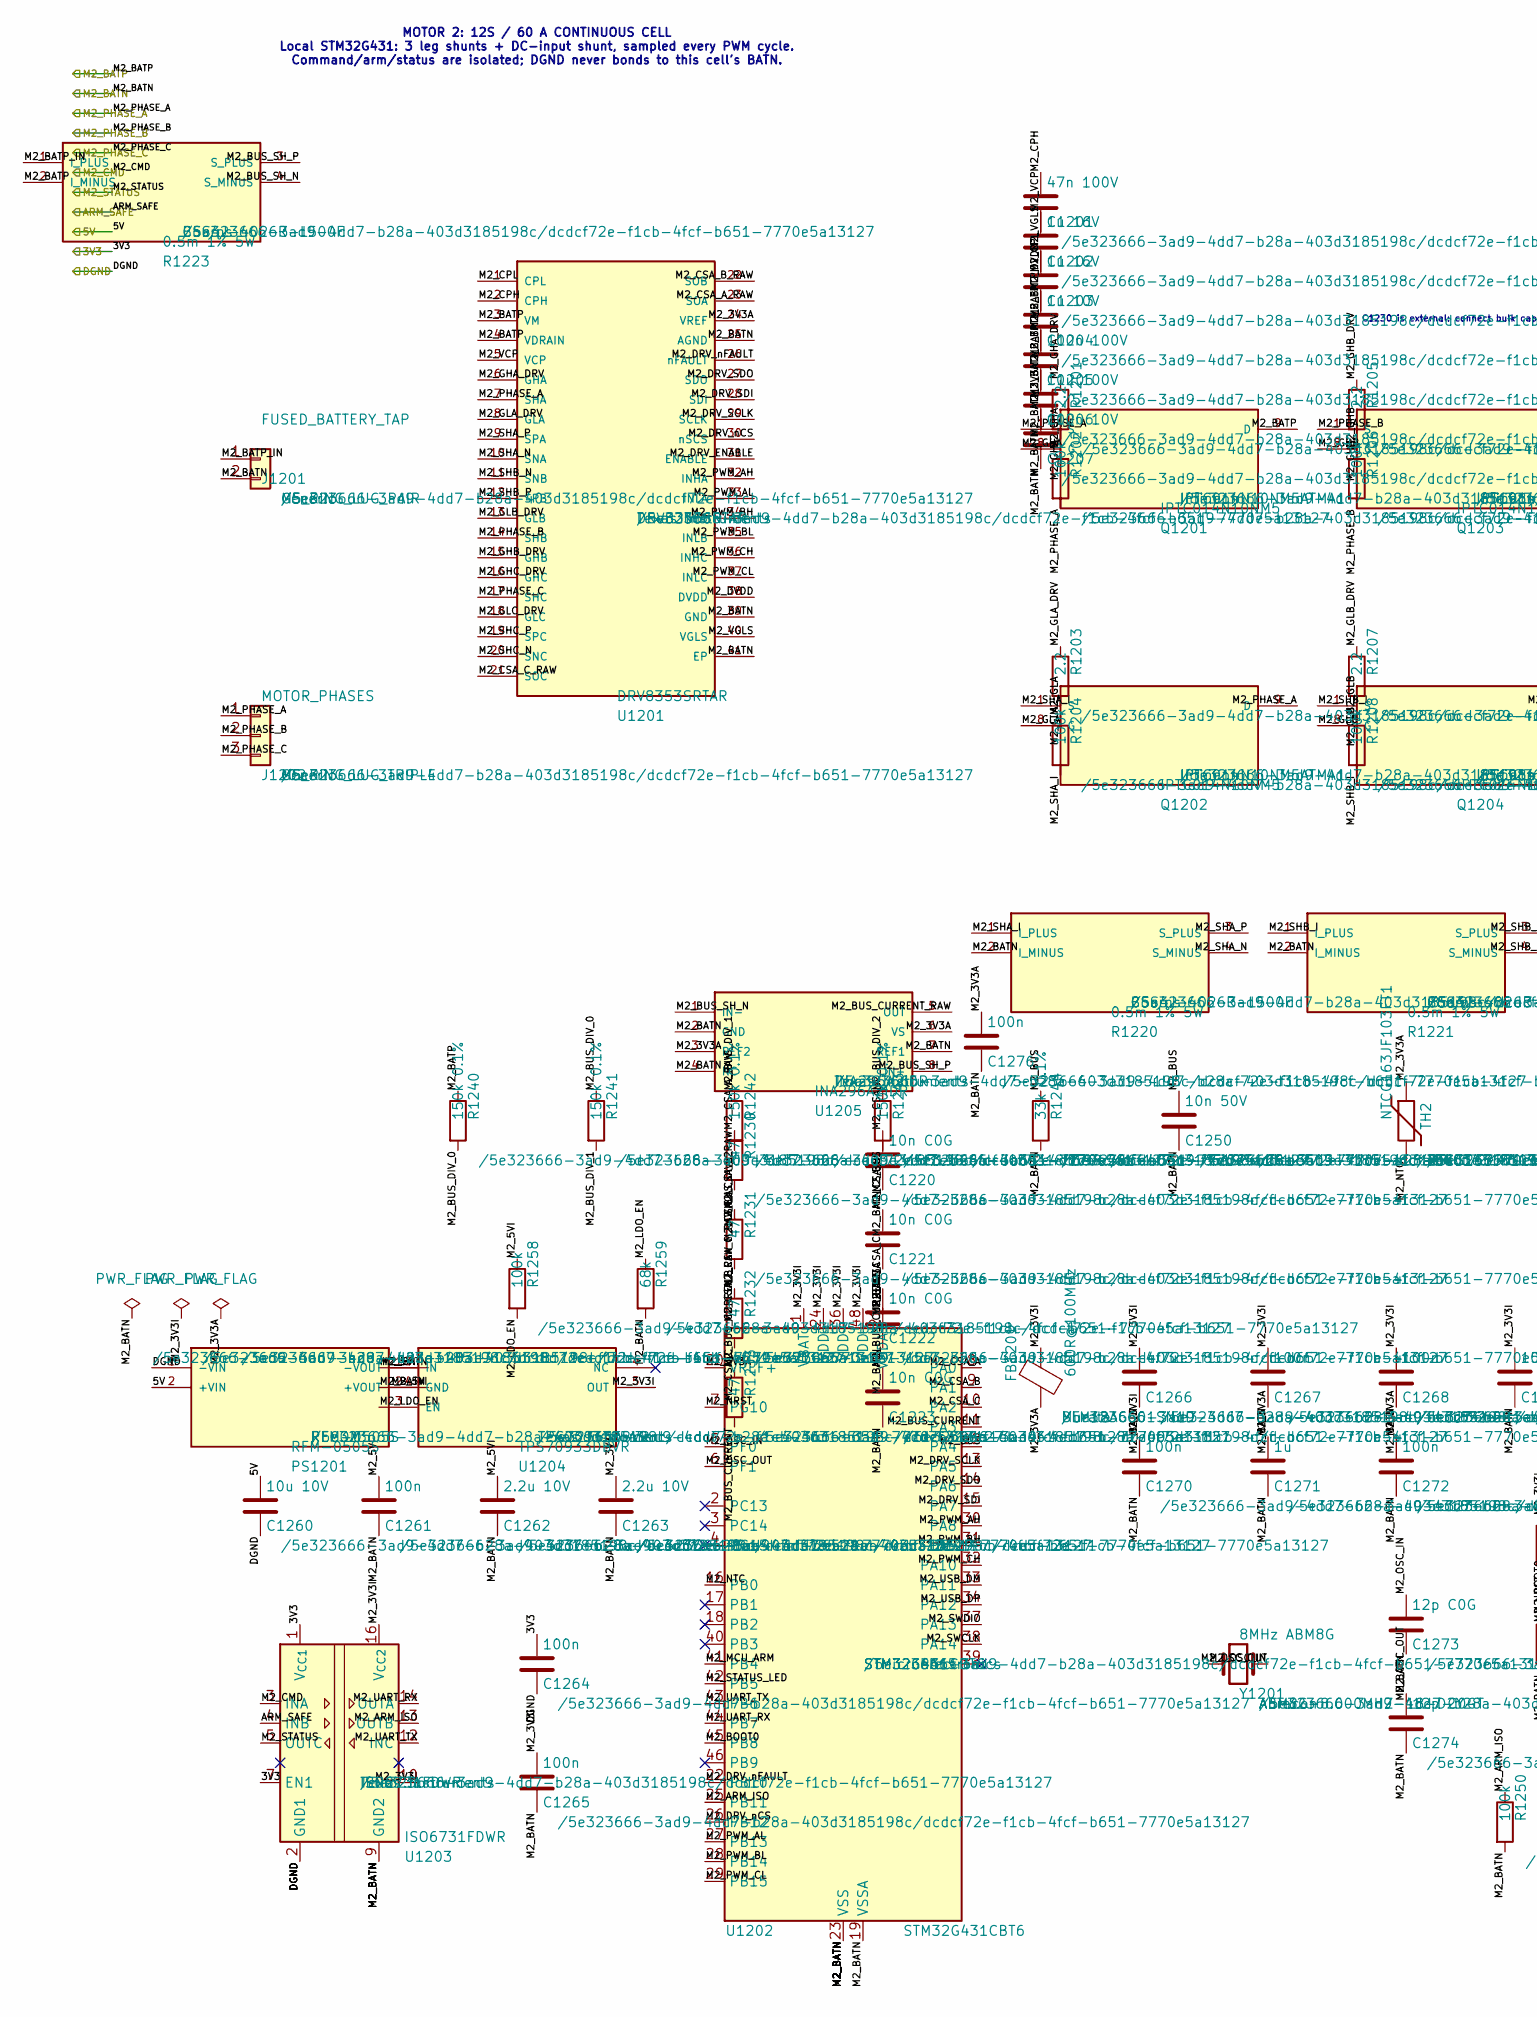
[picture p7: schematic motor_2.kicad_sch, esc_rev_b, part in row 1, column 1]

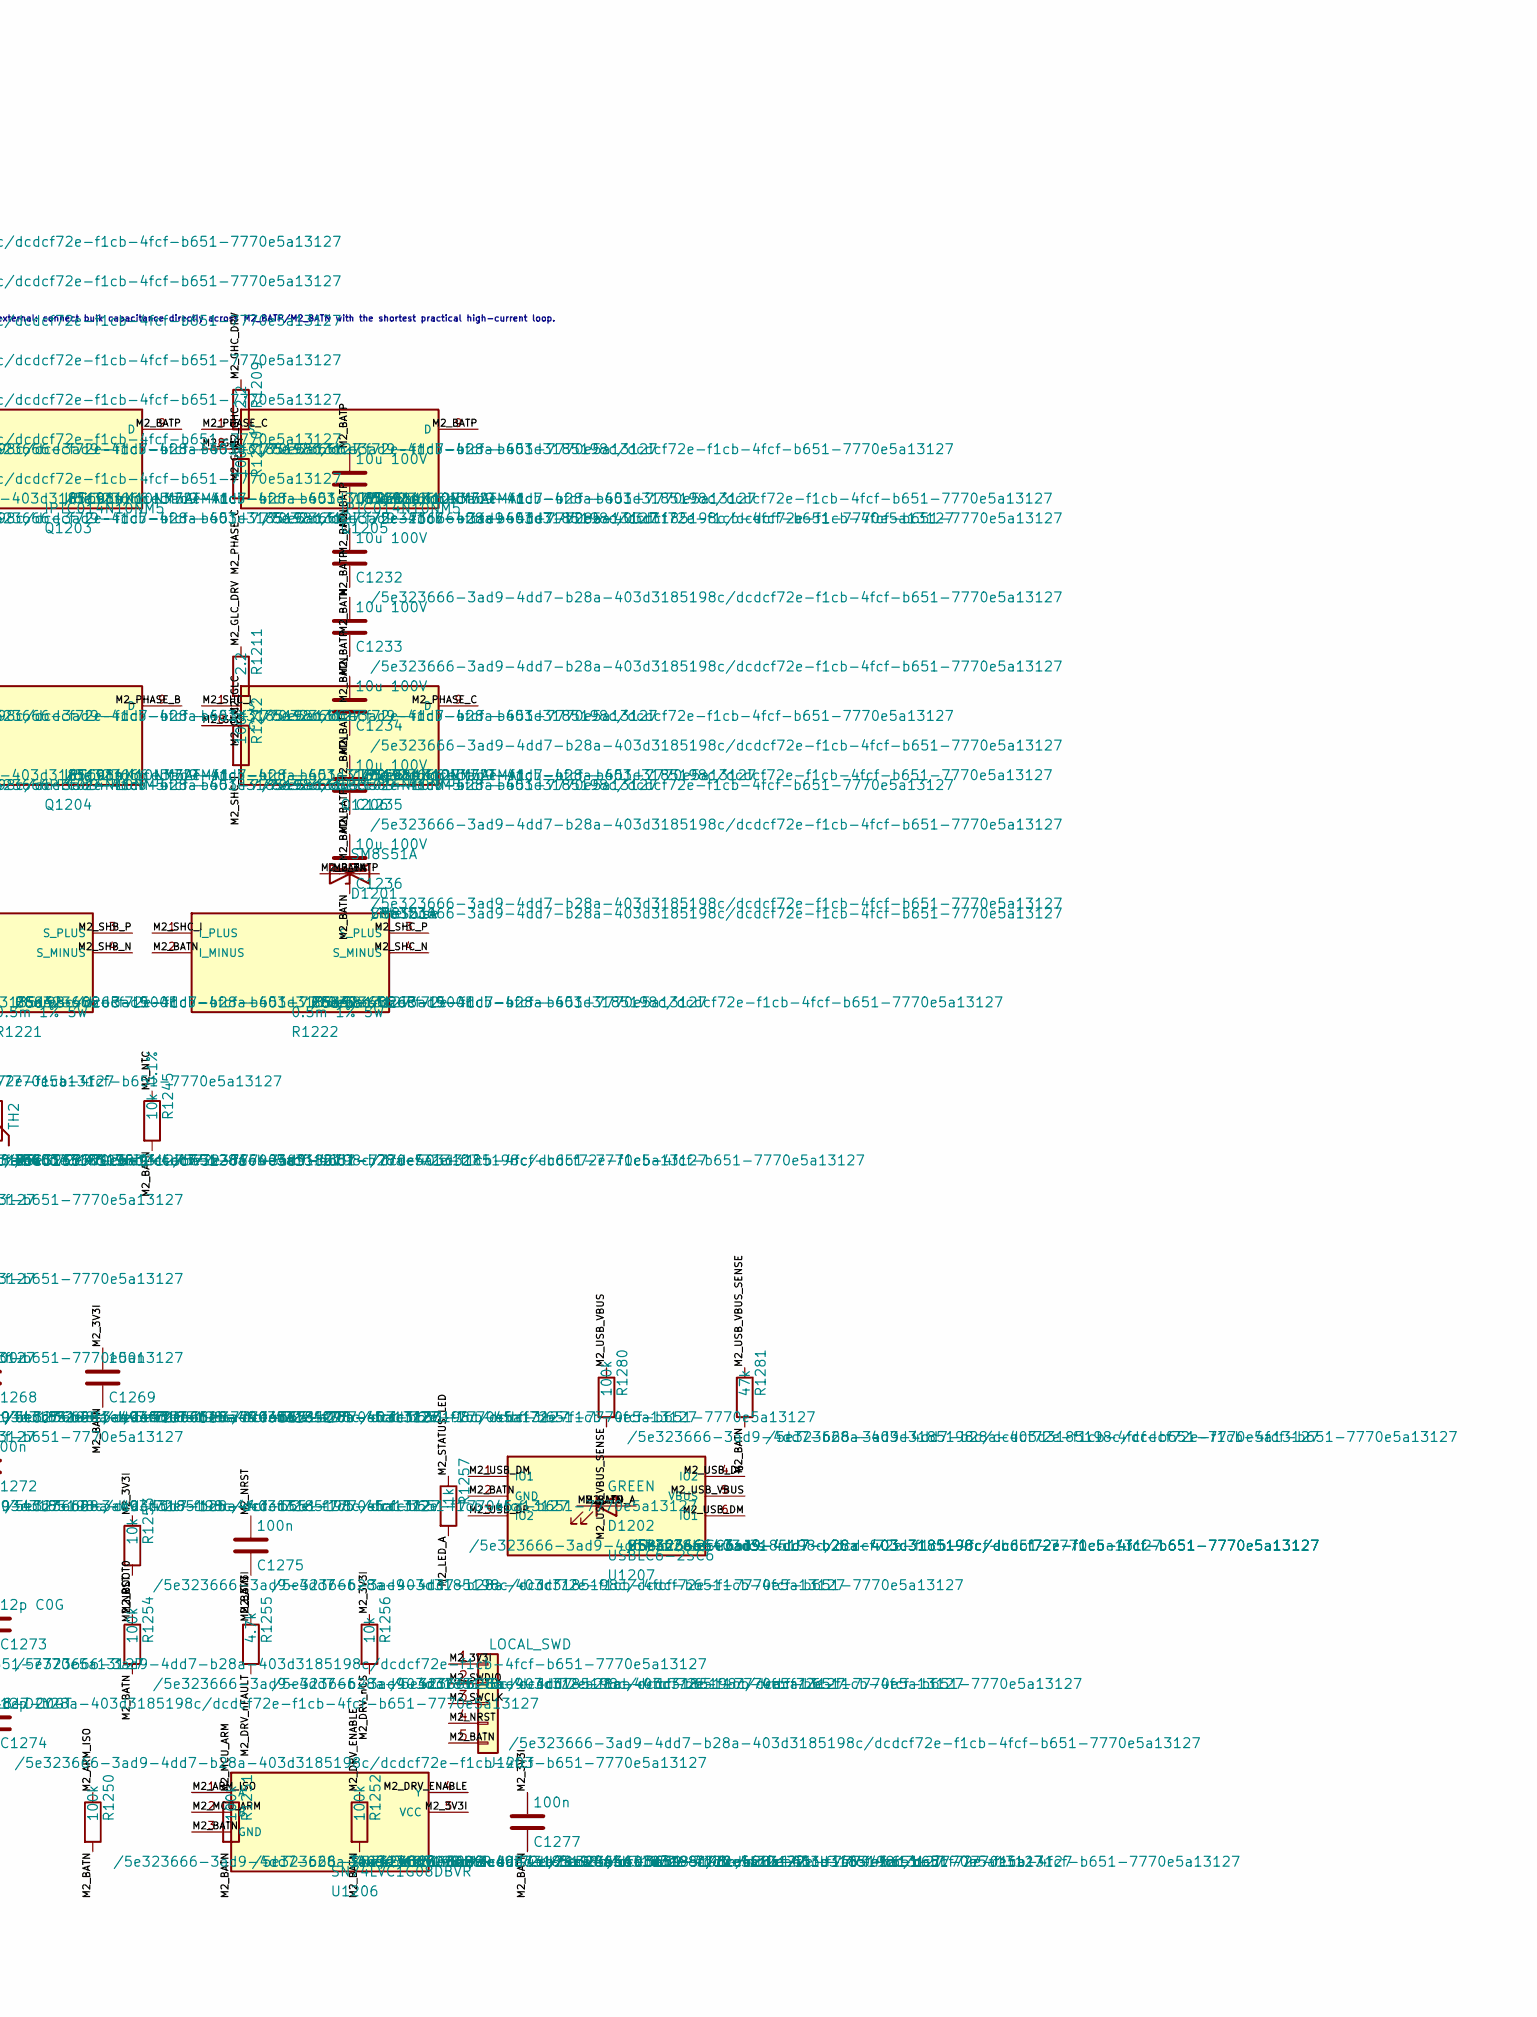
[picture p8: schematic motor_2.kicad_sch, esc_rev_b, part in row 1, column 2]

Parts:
C1201: 47n 100V; C_0603_1608Metric
C1202, C1203: 1u 16V; C_0603_1608Metric
C1204: 1u 10V; C_0603_1608Metric
C1205: 100n 100V; C_0603_1608Metric
C1206, C1231, C1232, C1233, C1234, C1235, C1236: 10u 100V; C_1210_3225Metric
C1207: 100n 10V; C_0603_1608Metric
C1220, C1221, C1222, C1223: 10n C0G; C_0603_1608Metric
C1250: 10n 50V; C_0603_1608Metric
C1260: 10u 10V; C_0805_2012Metric
C1261, C1264, C1265, C1275, C1276, C1277: 100n; C_0603_1608Metric
C1262, C1263: 2.2u 10V; C_0603_1608Metric
C1266: 4.7u; C_0603_1608Metric
C1267, C1268, C1269, C1270, C1272: 100n; C_0402_1005Metric
C1271: 1u; C_0603_1608Metric
C1273, C1274: 12p C0G; C_0402_1005Metric
D1201: SM8S51A; DO-218AB_SM8S; MPN SM8S51A
D1202: GREEN; LED_0603_1608Metric
FB1201: 600R@100MHz; L_0603_1608Metric; MPN BLM18AG601SN1D
J1201: FUSED_BATTERY_TAP; POWER_LUG_M5_2P_P20; MPN M5_RING_LUG_PAIR
J1202: MOTOR_PHASES; POWER_LUG_M5_3P_P20; MPN M5_RING_LUG_TRIPLE
J1203: LOCAL_SWD; PinHeader_1x05_P1.27mm_Vertical
PS1201: RFM-0505S; RFM_SIP4_11.5x6_P2.54; MPN RFM-0505S
Q1201, Q1202, Q1203, Q1204, Q1205, Q1206: IPTC014N10NM5; PG-HDSOP-16_TOLT_IPTC; MPN IPTC014N10NM5ATMA1
R1201, R1203, R1205, R1207, R1209, R1211: 2.2; R_0603_1608Metric
R1202, R1204, R1206, R1208, R1210, R1212, R1250, R1251, R1252, R1254, R1258, R1280: 100k; R_0603_1608Metric
R1220, R1221, R1222, R1223: 0.5m 1% 5W; CSS4J-4026_Kelvin; MPN CSS4J-4026R-L500F
R1230, R1231, R1232, R1233: 47; R_0603_1608Metric
R1240, R1241, R1242, R1243: 150k 0.1%; R_1206_3216Metric
R1244: 33k 0.1%; R_0603_1608Metric
R1245: 10k 0.1%; R_0603_1608Metric
R1253, R1256: 10k; R_0603_1608Metric
R1255: 4.7k; R_0603_1608Metric
R1257: 1k; R_0603_1608Metric
R1259: 68k; R_0603_1608Metric
R1281: 47k; R_0603_1608Metric
TH2: NTCG163JF103FT1; R_0603_1608Metric; MPN NTCG163JF103FT1
U1201: DRV8353SRTAR; WQFN-40-EP_6x6_P0.5; MPN DRV8353SRTAR
U1202: STM32G431CBT6; LQFP-48_7x7mm_P0.5mm; MPN STM32G431CBT6
U1203: ISO6731FDWR; SOIC-16W_7.5x10.3mm_P1.27mm; MPN ISO6731FDWR
U1204: TPS70933DBVR; SOT-23-5; MPN TPS70933DBVR
U1205: INA296A2IDR; SOIC-8_3.9x4.9mm_P1.27mm; MPN INA296A2IDR
U1206: SN74LVC1G08DBVR; SOT-23-5; MPN SN74LVC1G08DBVR
U1207: USBLC6-2SC6; SOT-23-6; MPN USBLC6-2SC6
Y1201: 8MHz ABM8G; Crystal_SMD_3225-4Pin_3.2x2.5mm; MPN ABM8G-8.000MHZ-18-D2Y-T

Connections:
/3V3: C1264.1, U1203.1 (V_{CC1}), U1203.7 (EN1); also elsewhere on the board
/5V: C1260.1, PS1201.2 (+VIN); also elsewhere on the board
/ARM_SAFE: U1203.4 (INB); also elsewhere on the board
/DGND: C1260.2, C1264.2, PS1201.1 (-VIN), U1203.2 (GND1), U1203.8 (GND1); also elsewhere on the board
/M2_BATN: C1203.2, C1204.2, C1205.2, C1206.2, C1207.2, C1220.2, C1221.2, C1222.2, C1223.2, C1231.2, C1232.2, C1233.2, C1234.2, C1235.2, C1236.2, C1250.2, C1261.2, C1262.2, C1263.2, C1265.2, C1266.2, C1267.2, C1268.2, C1269.2, C1270.2, C1271.2, C1272.2, C1273.2, C1274.2, C1275.2, C1276.2, C1277.2, D1201.1 (A1), D1202.1 (K), J1201.2, J1203.5, PS1201.3 (-VOUT), R1220.2 (I_MINUS), R1221.2 (I_MINUS), R1222.2 (I_MINUS), R1244.2, R1245.2, R1250.2, R1251.2, R1252.2, R1254.2, R1259.2, R1281.2, U1201.25 (AGND), U1201.39 (GND), U1201.41 (EP), U1202.19 (VSSA), U1202.23 (VSS), U1202.35 (VSS), U1202.47 (VSS), U1203.9 (GND2), U1203.15 (GND2), U1204.2 (GND), U1205.2 (GND), U1205.4 (NC), U1205.7 (REF1), U1206.3 (GND), U1207.2 (GND); also elsewhere on the board
/M2_BATP: C1202.2, C1205.1, C1206.1, C1231.1, C1232.1, C1233.1, C1234.1, C1235.1, C1236.1, D1201.2 (A2), Q1201.9 (D), Q1203.9 (D), Q1205.9 (D), R1223.2 (I_MINUS), R1240.1, U1201.3 (VM), U1201.4 (VDRAIN); also elsewhere on the board
/M2_CMD: U1203.3 (INA); also elsewhere on the board
/M2_PHASE_A: J1202.1, Q1201.1 (S), Q1202.9 (D), R1202.2, U1201.7 (SHA)
/M2_PHASE_B: J1202.2, Q1203.1 (S), Q1204.9 (D), R1206.2, U1201.14 (SHB)
/M2_PHASE_C: J1202.3, Q1205.1 (S), Q1206.9 (D), R1210.2, U1201.17 (SHC)
/M2_STATUS: U1203.5 (OUTC); also elsewhere on the board
/Motor 2 power cell/M2_3V3A: C1207.1, C1271.1, C1272.1, C1276.1, FB1201.2, TH2.1, U1201.24 (VREF), U1202.20 (VREF+), U1202.21 (VDDA), U1205.3 (REF2), U1205.6 (VS)
/Motor 2 power cell/M2_3V3I: C1263.1, C1265.1, C1266.1, C1267.1, C1268.1, C1269.1, C1270.1, C1277.1, FB1201.1, J1203.1, R1253.1, R1255.1, R1256.1, U1202.1 (VBAT), U1202.24 (VDD), U1202.36 (VDD), U1202.48 (VDD), U1203.10 (EN2), U1203.16 (V_{CC2}), U1204.5 (OUT), U1206.5 (VCC)
/Motor 2 power cell/M2_5VI: C1261.1, C1262.1, PS1201.4 (+VOUT), R1258.1, U1204.1 (IN)
/Motor 2 power cell/M2_ARM_ISO: R1250.1, U1202.25 (PB11), U1203.13 (OUTB), U1206.1 (A)
/Motor 2 power cell/M2_BATP_IN: J1201.1, R1223.1 (I_PLUS)
/Motor 2 power cell/M2_BOOT0: R1254.1, U1202.45 (PB8)
/Motor 2 power cell/M2_BUS: C1250.1, R1243.2, R1244.1, U1202.12 (PA4)
/Motor 2 power cell/M2_BUS_CURRENT: C1223.1, R1233.2, U1202.11 (PA3)
/Motor 2 power cell/M2_BUS_CURRENT_RAW: R1233.1, U1205.5 (OUT)
/Motor 2 power cell/M2_BUS_DIV_0: R1240.2, R1241.1
/Motor 2 power cell/M2_BUS_DIV_1: R1241.2, R1242.1
/Motor 2 power cell/M2_BUS_DIV_2: R1242.2, R1243.1
/Motor 2 power cell/M2_BUS_SH_N: R1223.4 (S_MINUS), U1205.1 (IN-)
/Motor 2 power cell/M2_BUS_SH_P: R1223.3 (S_PLUS), U1205.8 (IN+)
/Motor 2 power cell/M2_CPH: C1201.1, U1201.2 (CPH)
/Motor 2 power cell/M2_CPL: C1201.2, U1201.1 (CPL)
/Motor 2 power cell/M2_CSA_A: C1220.1, R1230.2, U1202.8 (PA0)
/Motor 2 power cell/M2_CSA_A_RAW: R1230.1, U1201.23 (SOA)
/Motor 2 power cell/M2_CSA_B: C1221.1, R1231.2, U1202.9 (PA1)
/Motor 2 power cell/M2_CSA_B_RAW: R1231.1, U1201.22 (SOB)
/Motor 2 power cell/M2_CSA_C: C1222.1, R1232.2, U1202.10 (PA2)
/Motor 2 power cell/M2_CSA_C_RAW: R1232.1, U1201.21 (SOC)
/Motor 2 power cell/M2_DRV_ENABLE: R1252.1, U1201.31 (ENABLE), U1206.4 (Y)
/Motor 2 power cell/M2_DRV_SCLK: U1201.29 (SCLK), U1202.13 (PA5)
/Motor 2 power cell/M2_DRV_SDI: U1201.28 (SDI), U1202.15 (PA7)
/Motor 2 power cell/M2_DRV_SDO: U1201.27 (SDO), U1202.14 (PA6)
/Motor 2 power cell/M2_DRV_nCS: R1256.2, U1201.30 (nSCS), U1202.26 (PB12)
/Motor 2 power cell/M2_DRV_nFAULT: R1255.2, U1201.26 (nFAULT), U1202.22 (PB10)
/Motor 2 power cell/M2_DVDD: C1204.1, U1201.38 (DVDD)
/Motor 2 power cell/M2_GHA: Q1201.8 (G), R1201.2, R1202.1
/Motor 2 power cell/M2_GHA_DRV: R1201.1, U1201.6 (GHA)
/Motor 2 power cell/M2_GHB: Q1203.8 (G), R1205.2, R1206.1
/Motor 2 power cell/M2_GHB_DRV: R1205.1, U1201.15 (GHB)
/Motor 2 power cell/M2_GHC: Q1205.8 (G), R1209.2, R1210.1
/Motor 2 power cell/M2_GHC_DRV: R1209.1, U1201.16 (GHC)
/Motor 2 power cell/M2_GLA: Q1202.8 (G), R1203.2, R1204.1
/Motor 2 power cell/M2_GLA_DRV: R1203.1, U1201.8 (GLA)
/Motor 2 power cell/M2_GLB: Q1204.8 (G), R1207.2, R1208.1
/Motor 2 power cell/M2_GLB_DRV: R1207.1, U1201.13 (GLB)
/Motor 2 power cell/M2_GLC: Q1206.8 (G), R1211.2, R1212.1
/Motor 2 power cell/M2_GLC_DRV: R1211.1, U1201.18 (GLC)
/Motor 2 power cell/M2_LDO_EN: R1258.2, R1259.1, U1204.3 (EN)
/Motor 2 power cell/M2_LED_A: D1202.2 (A), R1257.2
/Motor 2 power cell/M2_MCU_ARM: R1251.1, U1202.41 (PB4), U1206.2 (B)
/Motor 2 power cell/M2_NRST: C1275.1, J1203.4, R1253.2, U1202.7 (PG10)
/Motor 2 power cell/M2_NTC: R1245.1, TH2.2, U1202.16 (PB0)
/Motor 2 power cell/M2_OSC_IN: C1273.1, U1202.5 (PF0), Y1201.1
/Motor 2 power cell/M2_OSC_OUT: C1274.1, U1202.6 (PF1), Y1201.2
/Motor 2 power cell/M2_PWM_AH: U1201.32 (INHA), U1202.30 (PA8)
/Motor 2 power cell/M2_PWM_AL: U1201.33 (INLA), U1202.27 (PB13)
/Motor 2 power cell/M2_PWM_BH: U1201.34 (INHB), U1202.31 (PA9)
/Motor 2 power cell/M2_PWM_BL: U1201.35 (INLB), U1202.28 (PB14)
/Motor 2 power cell/M2_PWM_CH: U1201.36 (INHC), U1202.32 (PA10)
/Motor 2 power cell/M2_PWM_CL: U1201.37 (INLC), U1202.29 (PB15)
/Motor 2 power cell/M2_SHA_I: Q1202.1 (S), R1204.2, R1220.1 (I_PLUS)
/Motor 2 power cell/M2_SHA_N: R1220.4 (S_MINUS), U1201.10 (SNA)
/Motor 2 power cell/M2_SHA_P: R1220.3 (S_PLUS), U1201.9 (SPA)
/Motor 2 power cell/M2_SHB_I: Q1204.1 (S), R1208.2, R1221.1 (I_PLUS)
/Motor 2 power cell/M2_SHB_N: R1221.4 (S_MINUS), U1201.11 (SNB)
/Motor 2 power cell/M2_SHB_P: R1221.3 (S_PLUS), U1201.12 (SPB)
/Motor 2 power cell/M2_SHC_I: Q1206.1 (S), R1212.2, R1222.1 (I_PLUS)
/Motor 2 power cell/M2_SHC_N: R1222.4 (S_MINUS), U1201.20 (SNC)
/Motor 2 power cell/M2_SHC_P: R1222.3 (S_PLUS), U1201.19 (SPC)
/Motor 2 power cell/M2_STATUS_LED: R1257.1, U1202.42 (PB5)
/Motor 2 power cell/M2_SWCLK: J1203.3, U1202.38 (PA14)
/Motor 2 power cell/M2_SWDIO: J1203.2, U1202.37 (PA13)
/Motor 2 power cell/M2_UART_RX: U1202.44 (PB7), U1203.14 (OUTA)
/Motor 2 power cell/M2_UART_TX: U1202.43 (PB6), U1203.12 (INC)
/Motor 2 power cell/M2_USB_DM: U1202.33 (PA11), U1207.1 (IO1), U1207.6 (IO1)
/Motor 2 power cell/M2_USB_DP: U1202.34 (PA12), U1207.3 (IO2), U1207.4 (IO2)
/Motor 2 power cell/M2_USB_VBUS: R1280.1, U1207.5 (VBUS)
/Motor 2 power cell/M2_USB_VBUS_SENSE: R1280.2, R1281.1
/Motor 2 power cell/M2_VCP: C1202.1, U1201.5 (VCP)
/Motor 2 power cell/M2_VGLS: C1203.1, U1201.40 (VGLS)

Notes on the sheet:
MOTOR 2: 12S / 60 A CONTINUOUS CELL Local STM32G431: 3 leg shunts + DC-input shunt, sampled every PWM cycle. Command/arm/status are isolated; DGND never bonds to this cell's BATN.
C1230 is external: connect bulk capacitance directly across M2_BATP/M2_BATN with the shortest practical high-current loop.

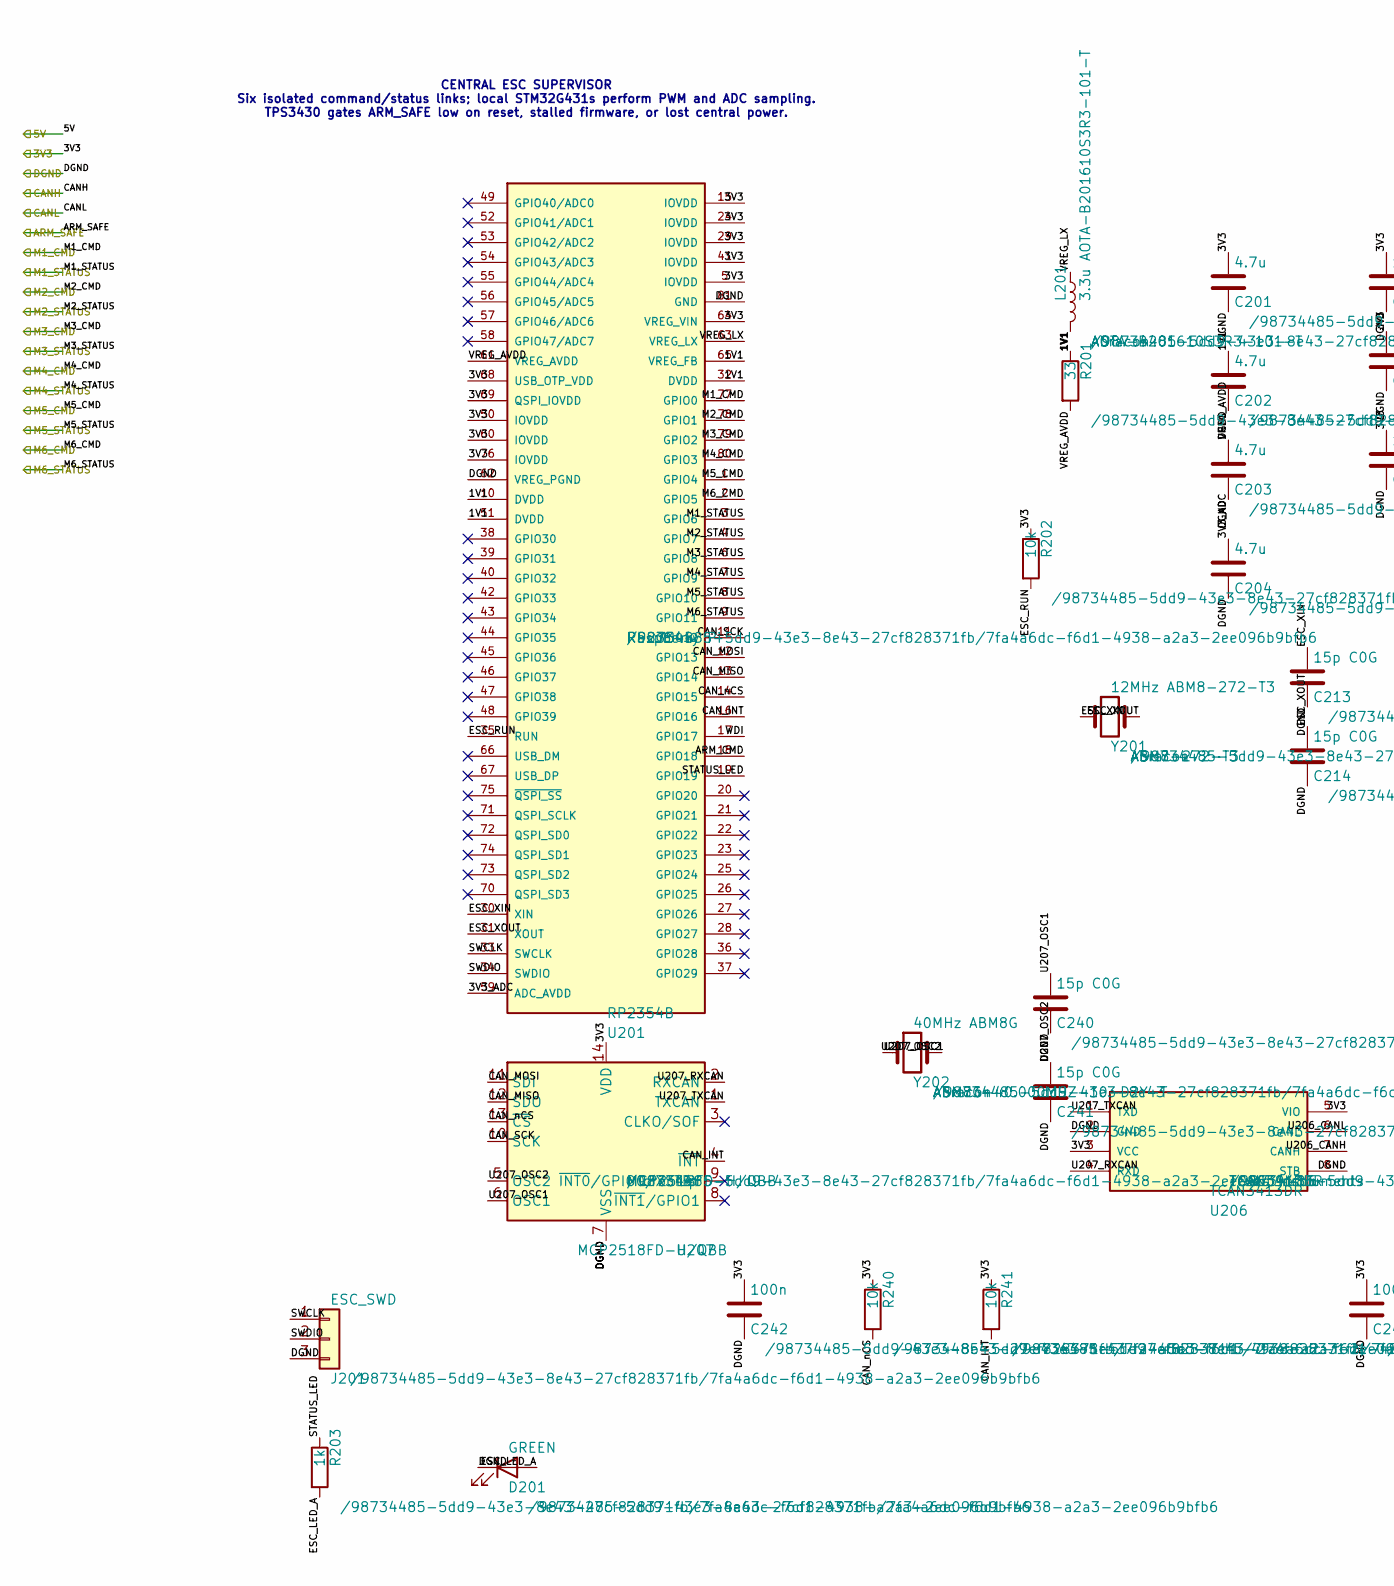
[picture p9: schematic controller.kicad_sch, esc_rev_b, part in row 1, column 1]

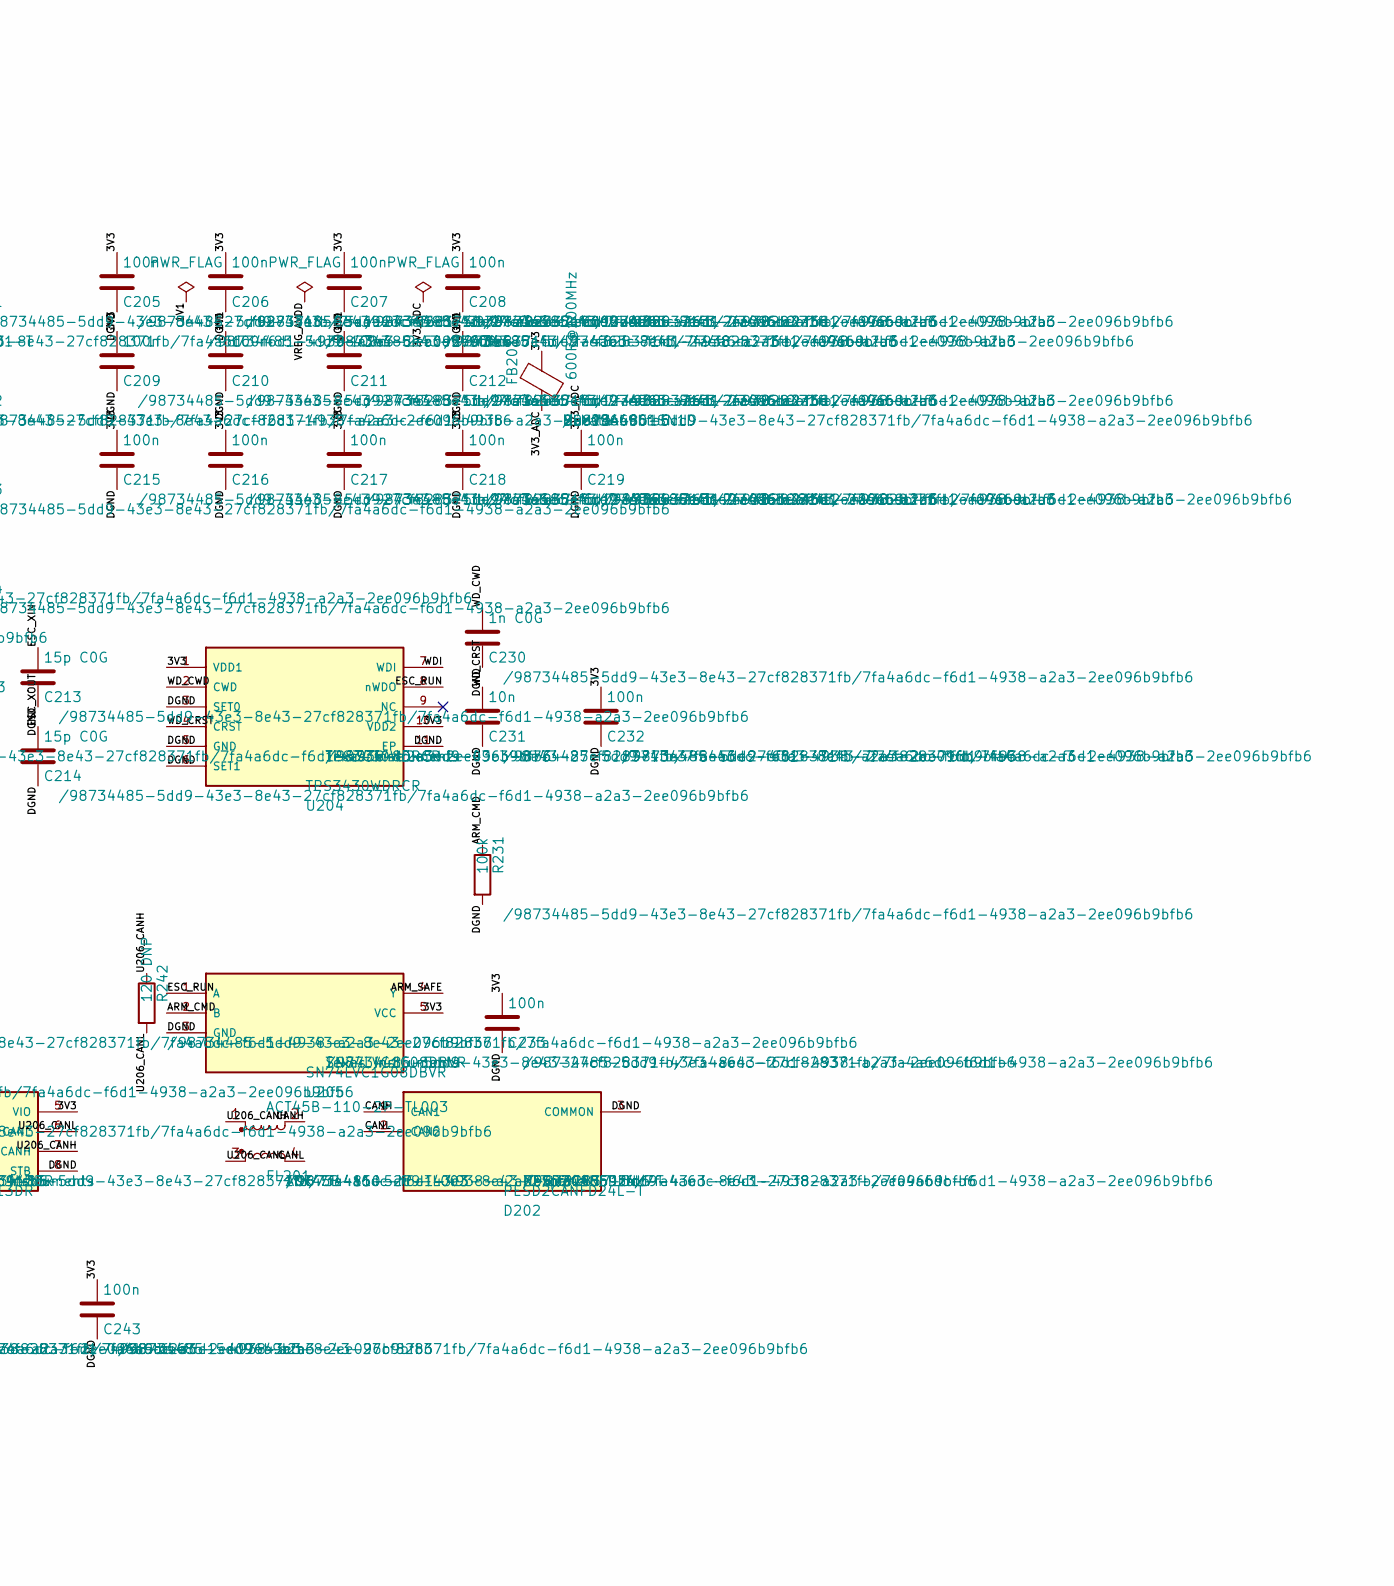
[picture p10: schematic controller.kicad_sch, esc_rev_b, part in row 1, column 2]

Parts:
C201, C202, C203, C204: 4.7u; C_0402_1005Metric
C205, C206, C207, C208, C209, C210, C211, C212, C215, C216, C217, C218, C219: 100n; C_0402_1005Metric
C213, C214, C240, C241: 15p C0G; C_0402_1005Metric
C230: 1n C0G; C_0603_1608Metric
C231: 10n; C_0603_1608Metric
C232, C233, C242, C243: 100n; C_0603_1608Metric
D201: GREEN; LED_0603_1608Metric
D202: PESD2CANFD24L-T; SOT-23; MPN PESD2CANFD24L-T
FB201: 600R@100MHz; L_0603_1608Metric; MPN BLM18AG601SN1D
FL201: ACT45B-110-2P-TL003; L_CommonModeChoke_Coilank_ACM4532; MPN ACT45B-110-2P-TL003
J201: ESC_SWD; JST_SH_SM03B-SRSS-TB_1x03-1MP_P1.00mm_Horizontal
L201: 3.3u AOTA-B201610S3R3-101-T; L_0805_2012Metric; MPN AOTA-B201610S3R3-101-T
R201: 33; R_0402_1005Metric
R202, R240, R241: 10k; R_0603_1608Metric
R203: 1k; R_0603_1608Metric
R231: 100k; R_0603_1608Metric
R242: 120 DNP; R_0603_1608Metric
U201: RP2354B; QFN-80-1EP_10x10mm_P0.4mm_EP3.4x3.4mm; MPN RP2354B
U204: TPS3430WDRCR; TPS3430_WSON10_EP; MPN TPS3430WDRCR
U205: SN74LVC1G08DBVR; SOT-23-5; MPN SN74LVC1G08DBVR
U206: TCAN3413DR; SOIC-8_3.9x4.9mm_P1.27mm; MPN TCAN3413DR
U207: MCP2518FD-H/QBB; DFN-14-1EP_3x4.5mm_P0.65mm_EP1.65x4.25mm; MPN MCP2518FD-H/QBB
Y201: 12MHz ABM8-272-T3; Crystal_SMD_3225-4Pin_3.2x2.5mm; MPN ABM8-272-T3
Y202: 40MHz ABM8G; Crystal_SMD_3225-4Pin_3.2x2.5mm; MPN ABM8G-40.000MHZ-10-D2Y-T

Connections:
/3V3: C201.1, C205.1, C206.1, C207.1, C208.1, C209.1, C215.1, C216.1, C217.1, C218.1, C232.1, C233.1, C242.1, C243.1, FB201.1, R202.1, R240.1, R241.1, U201.5 (IOVDD), U201.15 (IOVDD), U201.24 (IOVDD), U201.29 (IOVDD), U201.41 (IOVDD), U201.50 (IOVDD), U201.60 (IOVDD), U201.64 (VREG_VIN), U201.68 (USB_OTP_VDD), U201.69 (QSPI_IOVDD), U201.76 (IOVDD), U204.1 (VDD1), U204.10 (VDD2), U205.5 (VCC), U206.3 (VCC), U206.5 (VIO), U207.14 (VDD); also elsewhere on the board
/ARM_SAFE: U205.4 (Y); also elsewhere on the board
/CANH: D202.1 (CAN1), FL201.2; also elsewhere on the board
/CANL: D202.2 (CAN2), FL201.4; also elsewhere on the board
/Controller and ADC/1V1: C202.1, C210.1, C211.1, C212.1, L201.2, R201.1, U201.10 (DVDD), U201.32 (DVDD), U201.51 (DVDD), U201.65 (VREG_FB)
/Controller and ADC/3V3_ADC: C204.1, C219.1, FB201.2, U201.59 (ADC_AVDD)
/Controller and ADC/ARM_CMD: R231.1, U201.18 (GPIO18), U205.2 (B)
/Controller and ADC/CAN_INT: R241.2, U201.16 (GPIO16), U207.4 (~INT)
/Controller and ADC/CAN_MISO: U201.13 (GPIO14), U207.12 (SDO)
/Controller and ADC/CAN_MOSI: U201.12 (GPIO13), U207.11 (SDI)
/Controller and ADC/CAN_SCK: U201.11 (GPIO12), U207.10 (SCK)
/Controller and ADC/CAN_nCS: R240.2, U201.14 (GPIO15), U207.13 (~CS)
/Controller and ADC/CTRL_USB_DM_MCU: U201.66 (USB_DM); also elsewhere on the board
/Controller and ADC/CTRL_USB_DP_MCU: U201.67 (USB_DP); also elsewhere on the board
/Controller and ADC/CTRL_USB_VBUS_SENSE: U201.20 (GPIO20); also elsewhere on the board
/Controller and ADC/ESC_LED_A: D201.2 (A), R203.2
/Controller and ADC/ESC_RUN: R202.2, U201.35 (RUN), U204.8 (nWDO), U205.1 (A)
/Controller and ADC/ESC_XIN: C213.1, U201.30 (XIN), Y201.1
/Controller and ADC/ESC_XOUT: C214.1, U201.31 (XOUT), Y201.2
/Controller and ADC/STATUS_LED: R203.1, U201.19 (GPIO19)
/Controller and ADC/SWCLK: J201.1, U201.33 (SWCLK)
/Controller and ADC/SWDIO: J201.2, U201.34 (SWDIO)
/Controller and ADC/U206_CANH: FL201.1, R242.1, U206.7 (CANH)
/Controller and ADC/U206_CANL: FL201.3, R242.2, U206.6 (CANL)
/Controller and ADC/U207_OSC1: C240.1, U207.6 (OSC1), Y202.1
/Controller and ADC/U207_OSC2: C241.1, U207.5 (OSC2), Y202.2
/Controller and ADC/U207_RXCAN: U206.4 (RXD), U207.2 (RXCAN)
/Controller and ADC/U207_TXCAN: U206.1 (TXD), U207.1 (TXCAN)
/Controller and ADC/VREG_AVDD: C203.1, R201.2, U201.61 (VREG_AVDD)
/Controller and ADC/VREG_LX: L201.1, U201.63 (VREG_LX)
/Controller and ADC/WDI: U201.17 (GPIO17), U204.7 (WDI)
/Controller and ADC/WD_CRST: C231.1, U204.4 (CRST)
/Controller and ADC/WD_CWD: C230.1, U204.2 (CWD)
/DGND: C201.2, C202.2, C203.2, C204.2, C205.2, C206.2, C207.2, C208.2, C209.2, C210.2, C211.2, C212.2, C213.2, C214.2, C215.2, C216.2, C217.2, C218.2, C219.2, C230.2, C231.2, C232.2, C233.2, C240.2, C241.2, C242.2, C243.2, D201.1 (K), D202.3 (COMMON), J201.3, R231.2, U201.62 (VREG_PGND), U201.81 (GND), U204.3 (SET0), U204.5 (GND), U204.6 (SET1), U204.11 (EP), U205.3 (GND), U206.2 (GND), U206.8 (STB), U207.7 (VSS), U207.15 (VSS); also elsewhere on the board
/M1_CMD: U201.77 (GPIO0); also elsewhere on the board
/M1_STATUS: U201.3 (GPIO6); also elsewhere on the board
/M2_CMD: U201.78 (GPIO1); also elsewhere on the board
/M2_STATUS: U201.4 (GPIO7); also elsewhere on the board
/M3_CMD: U201.79 (GPIO2); also elsewhere on the board
/M3_STATUS: U201.6 (GPIO8); also elsewhere on the board
/M4_CMD: U201.80 (GPIO3); also elsewhere on the board
/M4_STATUS: U201.7 (GPIO9); also elsewhere on the board
/M5_CMD: U201.1 (GPIO4); also elsewhere on the board
/M5_STATUS: U201.8 (GPIO10); also elsewhere on the board
/M6_CMD: U201.2 (GPIO5); also elsewhere on the board
/M6_STATUS: U201.9 (GPIO11); also elsewhere on the board

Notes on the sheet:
CENTRAL ESC SUPERVISOR Six isolated command/status links; local STM32G431s perform PWM and ADC sampling. TPS3430 gates ARM_SAFE low on reset, stalled firmware, or lost central power.

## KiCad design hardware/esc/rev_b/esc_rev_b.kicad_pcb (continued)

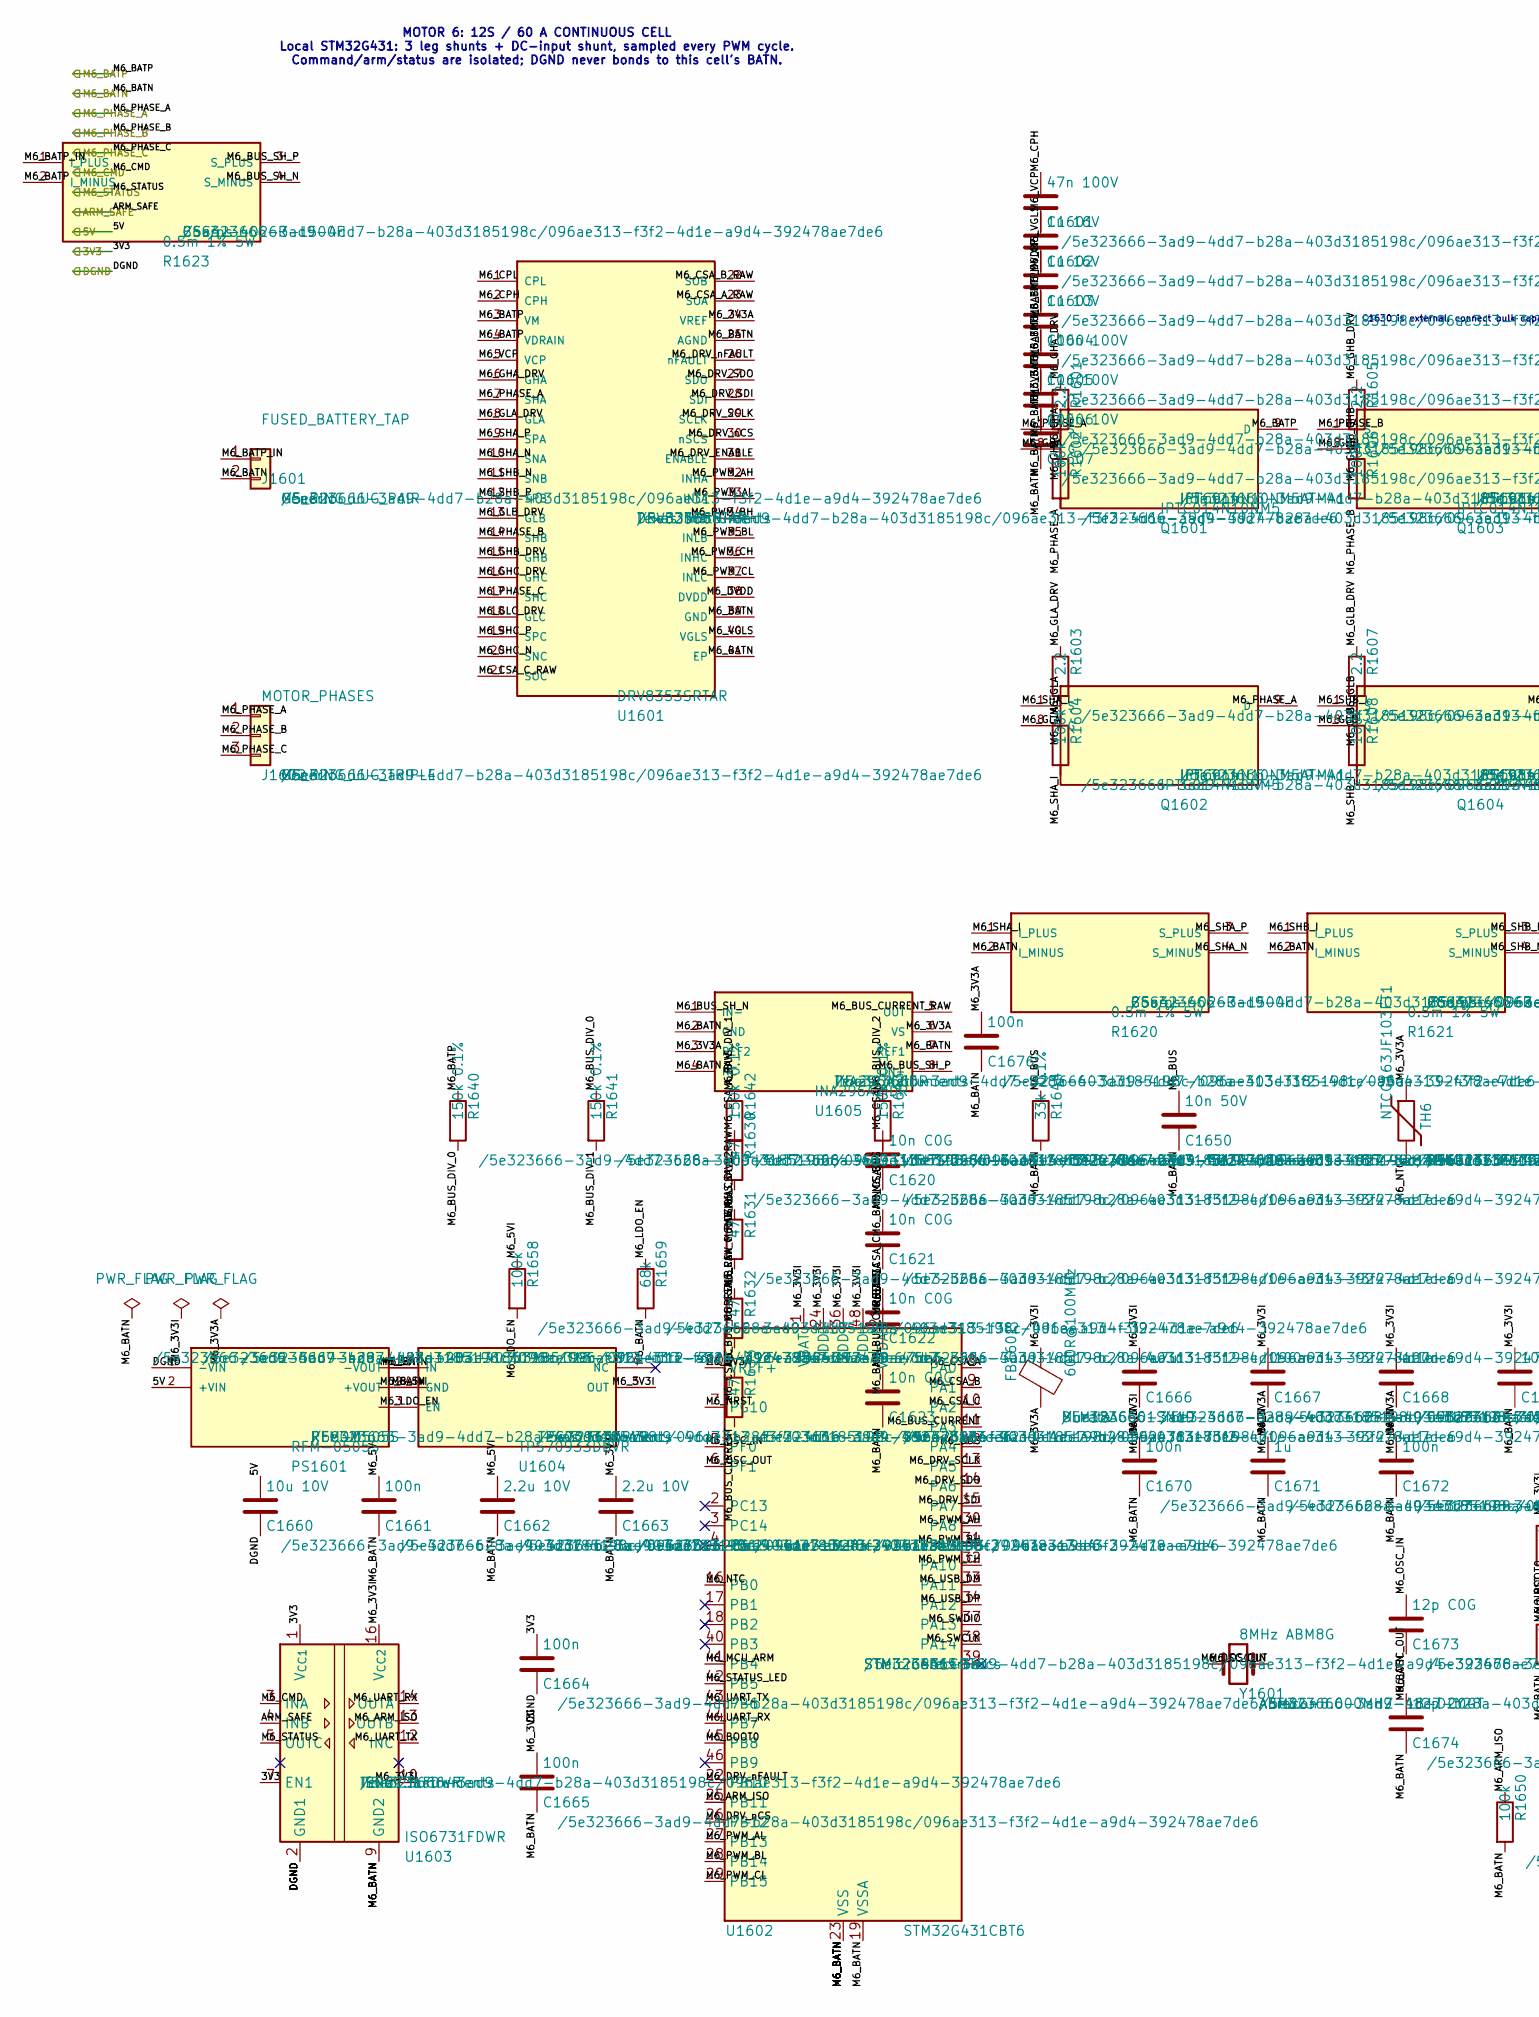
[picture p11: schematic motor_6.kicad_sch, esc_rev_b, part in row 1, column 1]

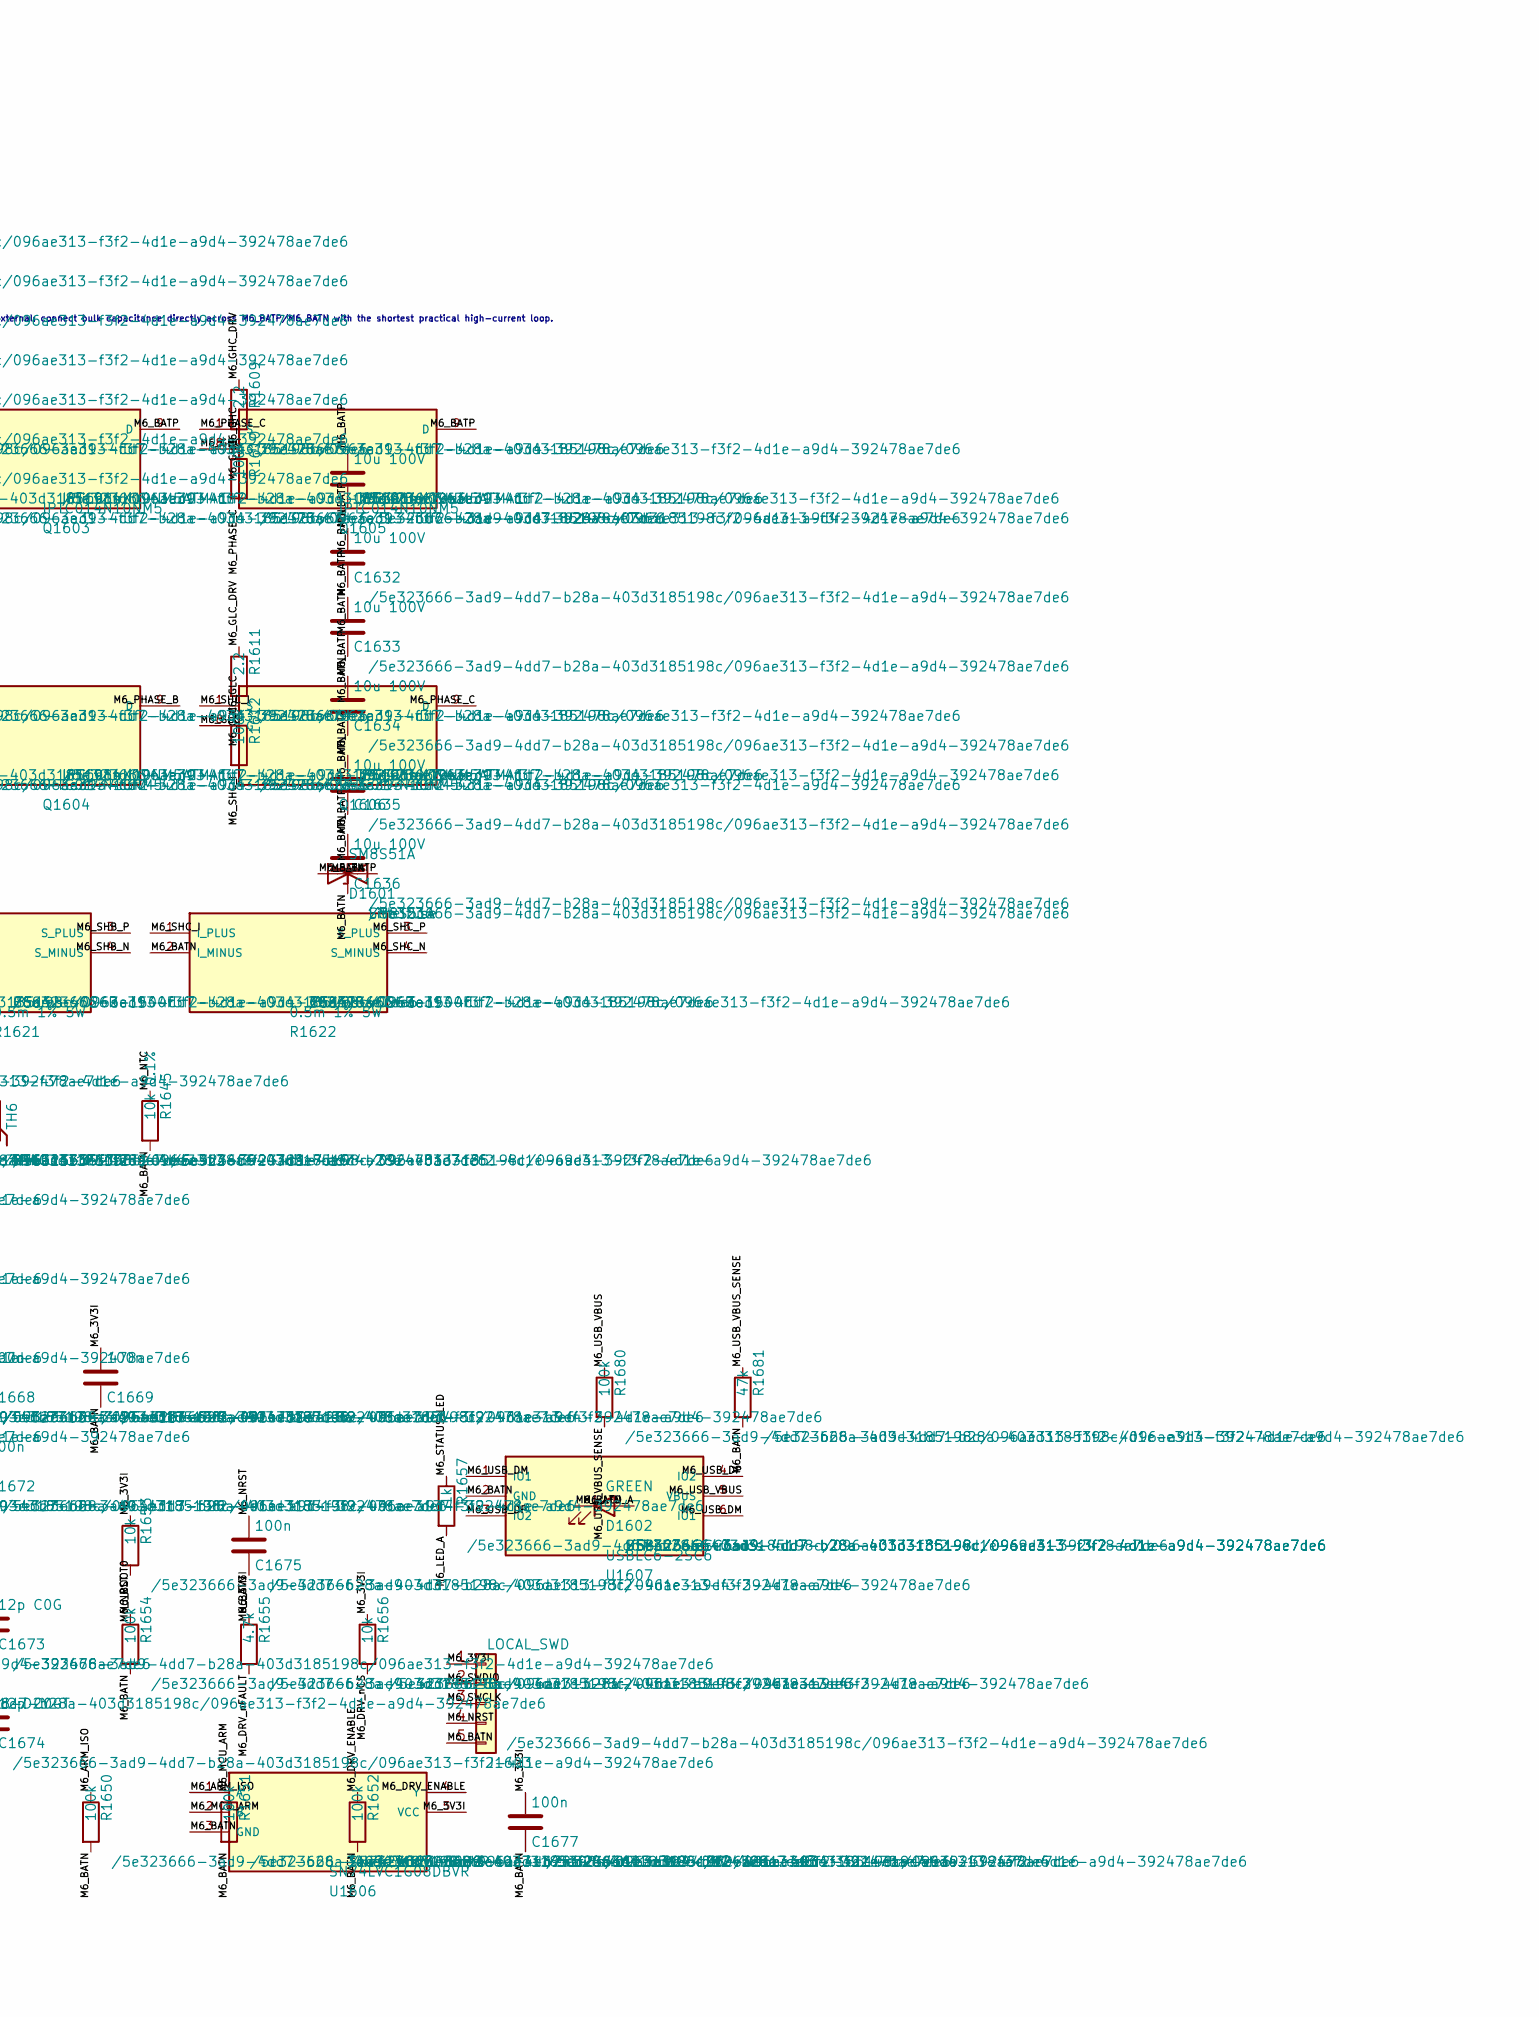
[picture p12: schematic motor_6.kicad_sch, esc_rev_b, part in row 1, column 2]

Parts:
C1601: 47n 100V; C_0603_1608Metric
C1602, C1603: 1u 16V; C_0603_1608Metric
C1604: 1u 10V; C_0603_1608Metric
C1605: 100n 100V; C_0603_1608Metric
C1606, C1631, C1632, C1633, C1634, C1635, C1636: 10u 100V; C_1210_3225Metric
C1607: 100n 10V; C_0603_1608Metric
C1620, C1621, C1622, C1623: 10n C0G; C_0603_1608Metric
C1650: 10n 50V; C_0603_1608Metric
C1660: 10u 10V; C_0805_2012Metric
C1661, C1664, C1665, C1675, C1676, C1677: 100n; C_0603_1608Metric
C1662, C1663: 2.2u 10V; C_0603_1608Metric
C1666: 4.7u; C_0603_1608Metric
C1667, C1668, C1669, C1670, C1672: 100n; C_0402_1005Metric
C1671: 1u; C_0603_1608Metric
C1673, C1674: 12p C0G; C_0402_1005Metric
D1601: SM8S51A; DO-218AB_SM8S; MPN SM8S51A
D1602: GREEN; LED_0603_1608Metric
FB1601: 600R@100MHz; L_0603_1608Metric; MPN BLM18AG601SN1D
J1601: FUSED_BATTERY_TAP; POWER_LUG_M5_2P_P20; MPN M5_RING_LUG_PAIR
J1602: MOTOR_PHASES; POWER_LUG_M5_3P_P20; MPN M5_RING_LUG_TRIPLE
J1603: LOCAL_SWD; PinHeader_1x05_P1.27mm_Vertical
PS1601: RFM-0505S; RFM_SIP4_11.5x6_P2.54; MPN RFM-0505S
Q1601, Q1602, Q1603, Q1604, Q1605, Q1606: IPTC014N10NM5; PG-HDSOP-16_TOLT_IPTC; MPN IPTC014N10NM5ATMA1
R1601, R1603, R1605, R1607, R1609, R1611: 2.2; R_0603_1608Metric
R1602, R1604, R1606, R1608, R1610, R1612, R1650, R1651, R1652, R1654, R1658, R1680: 100k; R_0603_1608Metric
R1620, R1621, R1622, R1623: 0.5m 1% 5W; CSS4J-4026_Kelvin; MPN CSS4J-4026R-L500F
R1630, R1631, R1632, R1633: 47; R_0603_1608Metric
R1640, R1641, R1642, R1643: 150k 0.1%; R_1206_3216Metric
R1644: 33k 0.1%; R_0603_1608Metric
R1645: 10k 0.1%; R_0603_1608Metric
R1653, R1656: 10k; R_0603_1608Metric
R1655: 4.7k; R_0603_1608Metric
R1657: 1k; R_0603_1608Metric
R1659: 68k; R_0603_1608Metric
R1681: 47k; R_0603_1608Metric
TH6: NTCG163JF103FT1; R_0603_1608Metric; MPN NTCG163JF103FT1
U1601: DRV8353SRTAR; WQFN-40-EP_6x6_P0.5; MPN DRV8353SRTAR
U1602: STM32G431CBT6; LQFP-48_7x7mm_P0.5mm; MPN STM32G431CBT6
U1603: ISO6731FDWR; SOIC-16W_7.5x10.3mm_P1.27mm; MPN ISO6731FDWR
U1604: TPS70933DBVR; SOT-23-5; MPN TPS70933DBVR
U1605: INA296A2IDR; SOIC-8_3.9x4.9mm_P1.27mm; MPN INA296A2IDR
U1606: SN74LVC1G08DBVR; SOT-23-5; MPN SN74LVC1G08DBVR
U1607: USBLC6-2SC6; SOT-23-6; MPN USBLC6-2SC6
Y1601: 8MHz ABM8G; Crystal_SMD_3225-4Pin_3.2x2.5mm; MPN ABM8G-8.000MHZ-18-D2Y-T

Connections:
/3V3: C1664.1, U1603.1 (V_{CC1}), U1603.7 (EN1); also elsewhere on the board
/5V: C1660.1, PS1601.2 (+VIN); also elsewhere on the board
/ARM_SAFE: U1603.4 (INB); also elsewhere on the board
/DGND: C1660.2, C1664.2, PS1601.1 (-VIN), U1603.2 (GND1), U1603.8 (GND1); also elsewhere on the board
/M6_BATN: C1603.2, C1604.2, C1605.2, C1606.2, C1607.2, C1620.2, C1621.2, C1622.2, C1623.2, C1631.2, C1632.2, C1633.2, C1634.2, C1635.2, C1636.2, C1650.2, C1661.2, C1662.2, C1663.2, C1665.2, C1666.2, C1667.2, C1668.2, C1669.2, C1670.2, C1671.2, C1672.2, C1673.2, C1674.2, C1675.2, C1676.2, C1677.2, D1601.1 (A1), D1602.1 (K), J1601.2, J1603.5, PS1601.3 (-VOUT), R1620.2 (I_MINUS), R1621.2 (I_MINUS), R1622.2 (I_MINUS), R1644.2, R1645.2, R1650.2, R1651.2, R1652.2, R1654.2, R1659.2, R1681.2, U1601.25 (AGND), U1601.39 (GND), U1601.41 (EP), U1602.19 (VSSA), U1602.23 (VSS), U1602.35 (VSS), U1602.47 (VSS), U1603.9 (GND2), U1603.15 (GND2), U1604.2 (GND), U1605.2 (GND), U1605.4 (NC), U1605.7 (REF1), U1606.3 (GND), U1607.2 (GND); also elsewhere on the board
/M6_BATP: C1602.2, C1605.1, C1606.1, C1631.1, C1632.1, C1633.1, C1634.1, C1635.1, C1636.1, D1601.2 (A2), Q1601.9 (D), Q1603.9 (D), Q1605.9 (D), R1623.2 (I_MINUS), R1640.1, U1601.3 (VM), U1601.4 (VDRAIN); also elsewhere on the board
/M6_CMD: U1603.3 (INA); also elsewhere on the board
/M6_PHASE_A: J1602.1, Q1601.1 (S), Q1602.9 (D), R1602.2, U1601.7 (SHA)
/M6_PHASE_B: J1602.2, Q1603.1 (S), Q1604.9 (D), R1606.2, U1601.14 (SHB)
/M6_PHASE_C: J1602.3, Q1605.1 (S), Q1606.9 (D), R1610.2, U1601.17 (SHC)
/M6_STATUS: U1603.5 (OUTC); also elsewhere on the board
/Motor 6 power cell/M6_3V3A: C1607.1, C1671.1, C1672.1, C1676.1, FB1601.2, TH6.1, U1601.24 (VREF), U1602.20 (VREF+), U1602.21 (VDDA), U1605.3 (REF2), U1605.6 (VS)
/Motor 6 power cell/M6_3V3I: C1663.1, C1665.1, C1666.1, C1667.1, C1668.1, C1669.1, C1670.1, C1677.1, FB1601.1, J1603.1, R1653.1, R1655.1, R1656.1, U1602.1 (VBAT), U1602.24 (VDD), U1602.36 (VDD), U1602.48 (VDD), U1603.10 (EN2), U1603.16 (V_{CC2}), U1604.5 (OUT), U1606.5 (VCC)
/Motor 6 power cell/M6_5VI: C1661.1, C1662.1, PS1601.4 (+VOUT), R1658.1, U1604.1 (IN)
/Motor 6 power cell/M6_ARM_ISO: R1650.1, U1602.25 (PB11), U1603.13 (OUTB), U1606.1 (A)
/Motor 6 power cell/M6_BATP_IN: J1601.1, R1623.1 (I_PLUS)
/Motor 6 power cell/M6_BOOT0: R1654.1, U1602.45 (PB8)
/Motor 6 power cell/M6_BUS: C1650.1, R1643.2, R1644.1, U1602.12 (PA4)
/Motor 6 power cell/M6_BUS_CURRENT: C1623.1, R1633.2, U1602.11 (PA3)
/Motor 6 power cell/M6_BUS_CURRENT_RAW: R1633.1, U1605.5 (OUT)
/Motor 6 power cell/M6_BUS_DIV_0: R1640.2, R1641.1
/Motor 6 power cell/M6_BUS_DIV_1: R1641.2, R1642.1
/Motor 6 power cell/M6_BUS_DIV_2: R1642.2, R1643.1
/Motor 6 power cell/M6_BUS_SH_N: R1623.4 (S_MINUS), U1605.1 (IN-)
/Motor 6 power cell/M6_BUS_SH_P: R1623.3 (S_PLUS), U1605.8 (IN+)
/Motor 6 power cell/M6_CPH: C1601.1, U1601.2 (CPH)
/Motor 6 power cell/M6_CPL: C1601.2, U1601.1 (CPL)
/Motor 6 power cell/M6_CSA_A: C1620.1, R1630.2, U1602.8 (PA0)
/Motor 6 power cell/M6_CSA_A_RAW: R1630.1, U1601.23 (SOA)
/Motor 6 power cell/M6_CSA_B: C1621.1, R1631.2, U1602.9 (PA1)
/Motor 6 power cell/M6_CSA_B_RAW: R1631.1, U1601.22 (SOB)
/Motor 6 power cell/M6_CSA_C: C1622.1, R1632.2, U1602.10 (PA2)
/Motor 6 power cell/M6_CSA_C_RAW: R1632.1, U1601.21 (SOC)
/Motor 6 power cell/M6_DRV_ENABLE: R1652.1, U1601.31 (ENABLE), U1606.4 (Y)
/Motor 6 power cell/M6_DRV_SCLK: U1601.29 (SCLK), U1602.13 (PA5)
/Motor 6 power cell/M6_DRV_SDI: U1601.28 (SDI), U1602.15 (PA7)
/Motor 6 power cell/M6_DRV_SDO: U1601.27 (SDO), U1602.14 (PA6)
/Motor 6 power cell/M6_DRV_nCS: R1656.2, U1601.30 (nSCS), U1602.26 (PB12)
/Motor 6 power cell/M6_DRV_nFAULT: R1655.2, U1601.26 (nFAULT), U1602.22 (PB10)
/Motor 6 power cell/M6_DVDD: C1604.1, U1601.38 (DVDD)
/Motor 6 power cell/M6_GHA: Q1601.8 (G), R1601.2, R1602.1
/Motor 6 power cell/M6_GHA_DRV: R1601.1, U1601.6 (GHA)
/Motor 6 power cell/M6_GHB: Q1603.8 (G), R1605.2, R1606.1
/Motor 6 power cell/M6_GHB_DRV: R1605.1, U1601.15 (GHB)
/Motor 6 power cell/M6_GHC: Q1605.8 (G), R1609.2, R1610.1
/Motor 6 power cell/M6_GHC_DRV: R1609.1, U1601.16 (GHC)
/Motor 6 power cell/M6_GLA: Q1602.8 (G), R1603.2, R1604.1
/Motor 6 power cell/M6_GLA_DRV: R1603.1, U1601.8 (GLA)
/Motor 6 power cell/M6_GLB: Q1604.8 (G), R1607.2, R1608.1
/Motor 6 power cell/M6_GLB_DRV: R1607.1, U1601.13 (GLB)
/Motor 6 power cell/M6_GLC: Q1606.8 (G), R1611.2, R1612.1
/Motor 6 power cell/M6_GLC_DRV: R1611.1, U1601.18 (GLC)
/Motor 6 power cell/M6_LDO_EN: R1658.2, R1659.1, U1604.3 (EN)
/Motor 6 power cell/M6_LED_A: D1602.2 (A), R1657.2
/Motor 6 power cell/M6_MCU_ARM: R1651.1, U1602.41 (PB4), U1606.2 (B)
/Motor 6 power cell/M6_NRST: C1675.1, J1603.4, R1653.2, U1602.7 (PG10)
/Motor 6 power cell/M6_NTC: R1645.1, TH6.2, U1602.16 (PB0)
/Motor 6 power cell/M6_OSC_IN: C1673.1, U1602.5 (PF0), Y1601.1
/Motor 6 power cell/M6_OSC_OUT: C1674.1, U1602.6 (PF1), Y1601.2
/Motor 6 power cell/M6_PWM_AH: U1601.32 (INHA), U1602.30 (PA8)
/Motor 6 power cell/M6_PWM_AL: U1601.33 (INLA), U1602.27 (PB13)
/Motor 6 power cell/M6_PWM_BH: U1601.34 (INHB), U1602.31 (PA9)
/Motor 6 power cell/M6_PWM_BL: U1601.35 (INLB), U1602.28 (PB14)
/Motor 6 power cell/M6_PWM_CH: U1601.36 (INHC), U1602.32 (PA10)
/Motor 6 power cell/M6_PWM_CL: U1601.37 (INLC), U1602.29 (PB15)
/Motor 6 power cell/M6_SHA_I: Q1602.1 (S), R1604.2, R1620.1 (I_PLUS)
/Motor 6 power cell/M6_SHA_N: R1620.4 (S_MINUS), U1601.10 (SNA)
/Motor 6 power cell/M6_SHA_P: R1620.3 (S_PLUS), U1601.9 (SPA)
/Motor 6 power cell/M6_SHB_I: Q1604.1 (S), R1608.2, R1621.1 (I_PLUS)
/Motor 6 power cell/M6_SHB_N: R1621.4 (S_MINUS), U1601.11 (SNB)
/Motor 6 power cell/M6_SHB_P: R1621.3 (S_PLUS), U1601.12 (SPB)
/Motor 6 power cell/M6_SHC_I: Q1606.1 (S), R1612.2, R1622.1 (I_PLUS)
/Motor 6 power cell/M6_SHC_N: R1622.4 (S_MINUS), U1601.20 (SNC)
/Motor 6 power cell/M6_SHC_P: R1622.3 (S_PLUS), U1601.19 (SPC)
/Motor 6 power cell/M6_STATUS_LED: R1657.1, U1602.42 (PB5)
/Motor 6 power cell/M6_SWCLK: J1603.3, U1602.38 (PA14)
/Motor 6 power cell/M6_SWDIO: J1603.2, U1602.37 (PA13)
/Motor 6 power cell/M6_UART_RX: U1602.44 (PB7), U1603.14 (OUTA)
/Motor 6 power cell/M6_UART_TX: U1602.43 (PB6), U1603.12 (INC)
/Motor 6 power cell/M6_USB_DM: U1602.33 (PA11), U1607.1 (IO1), U1607.6 (IO1)
/Motor 6 power cell/M6_USB_DP: U1602.34 (PA12), U1607.3 (IO2), U1607.4 (IO2)
/Motor 6 power cell/M6_USB_VBUS: R1680.1, U1607.5 (VBUS)
/Motor 6 power cell/M6_USB_VBUS_SENSE: R1680.2, R1681.1
/Motor 6 power cell/M6_VCP: C1602.1, U1601.5 (VCP)
/Motor 6 power cell/M6_VGLS: C1603.1, U1601.40 (VGLS)

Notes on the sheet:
MOTOR 6: 12S / 60 A CONTINUOUS CELL Local STM32G431: 3 leg shunts + DC-input shunt, sampled every PWM cycle. Command/arm/status are isolated; DGND never bonds to this cell's BATN.
C1630 is external: connect bulk capacitance directly across M6_BATP/M6_BATN with the shortest practical high-current loop.

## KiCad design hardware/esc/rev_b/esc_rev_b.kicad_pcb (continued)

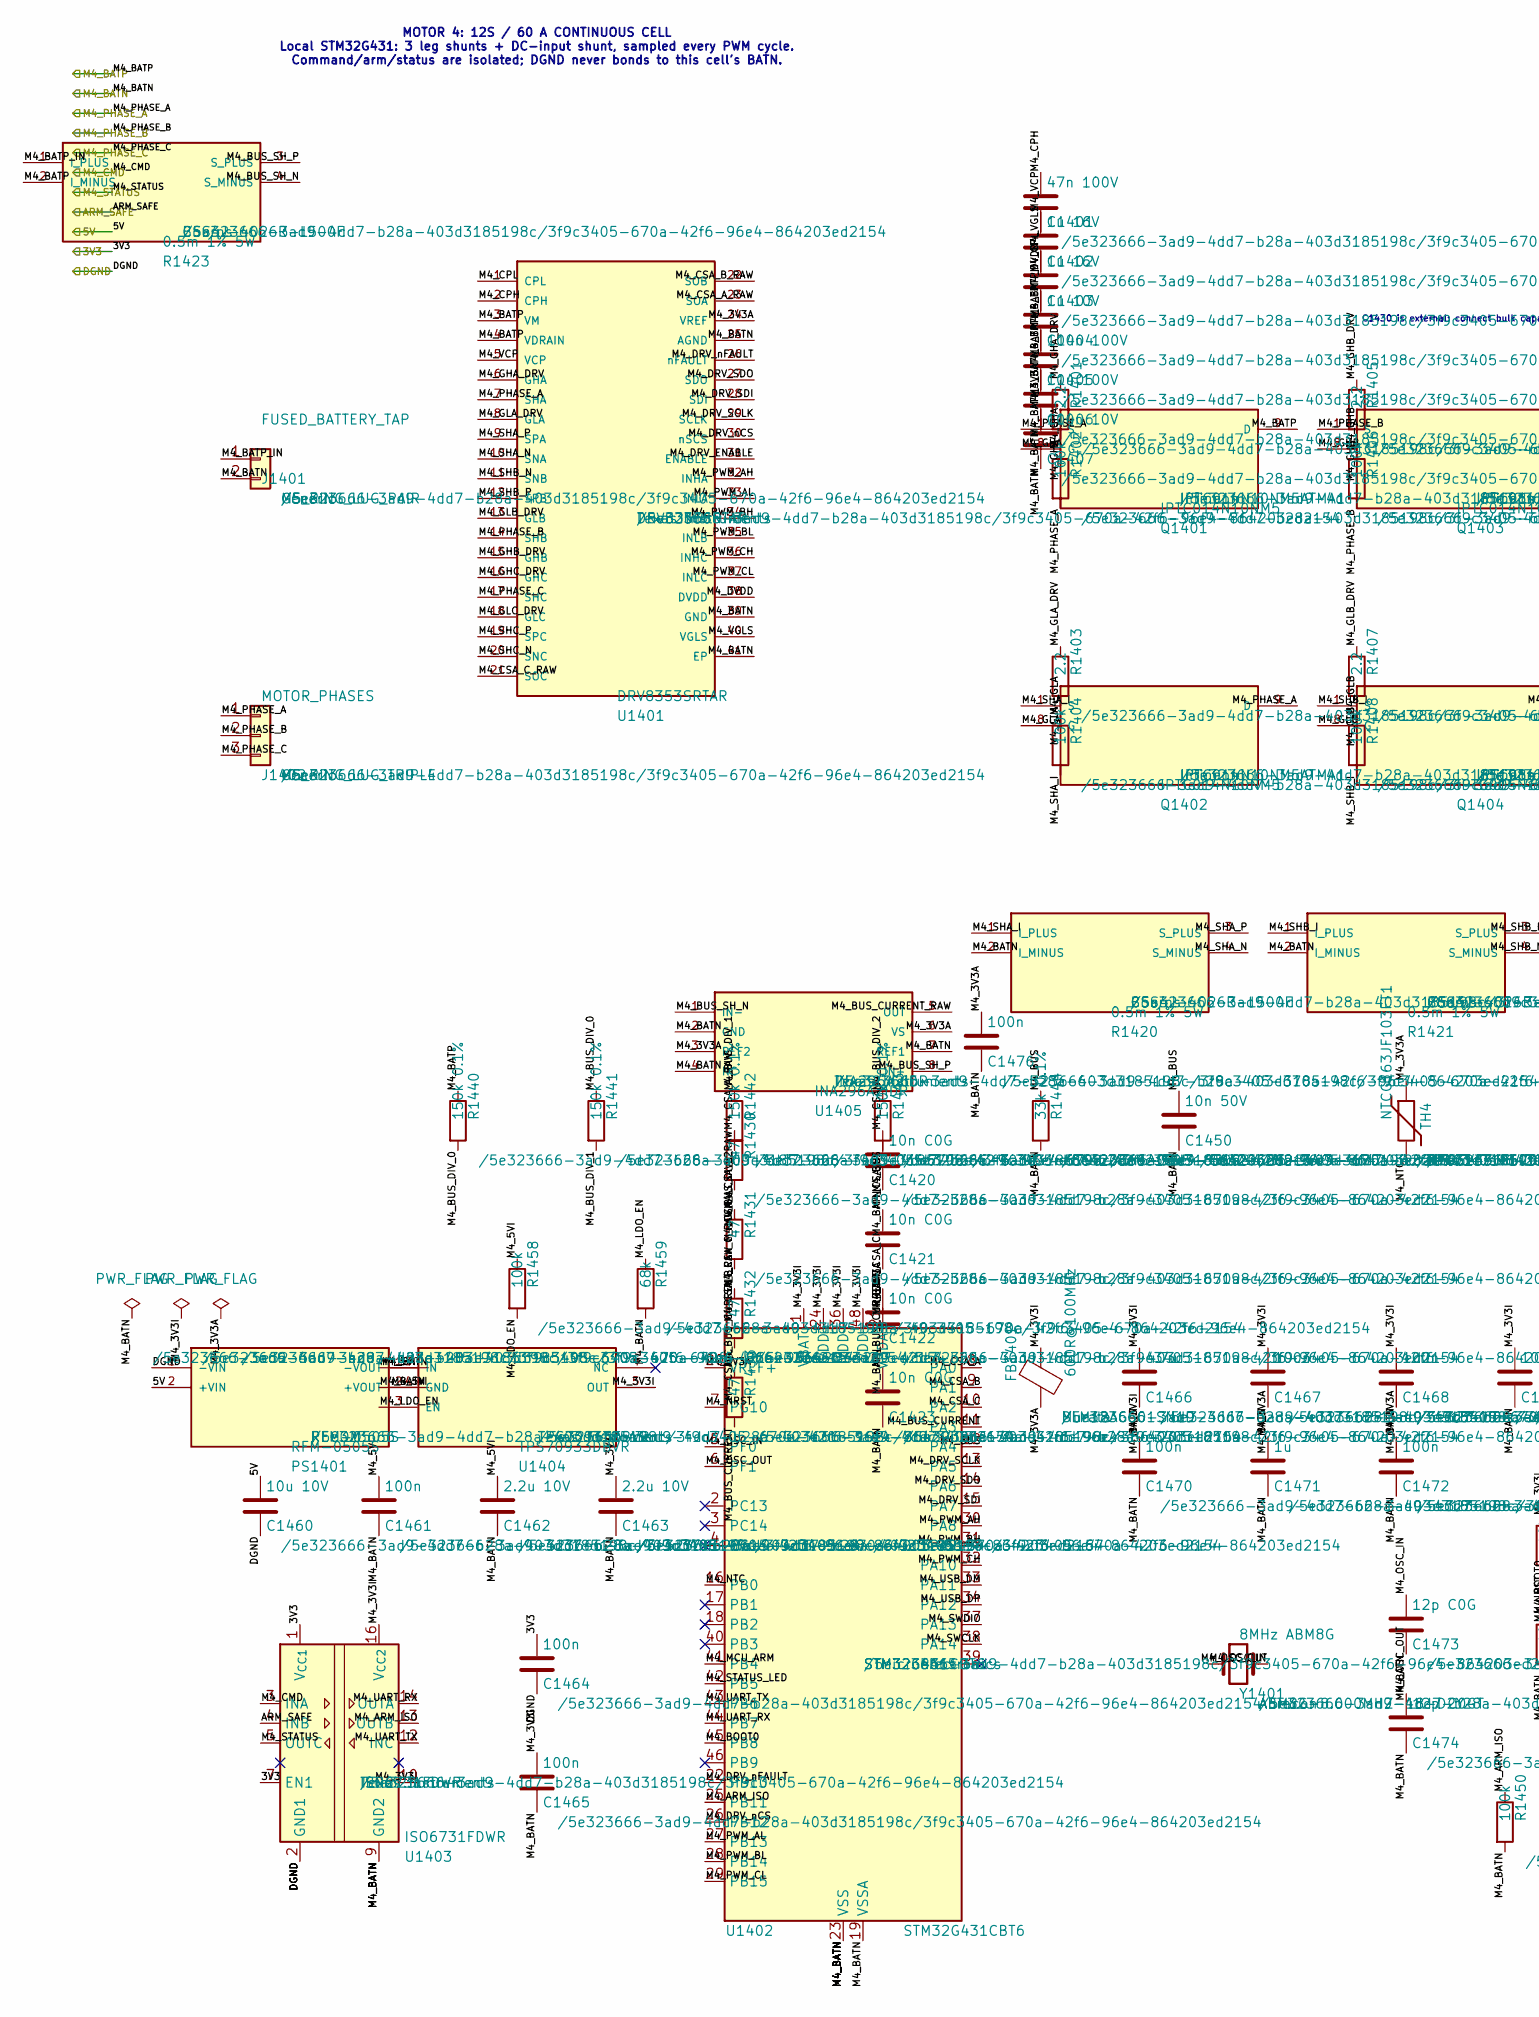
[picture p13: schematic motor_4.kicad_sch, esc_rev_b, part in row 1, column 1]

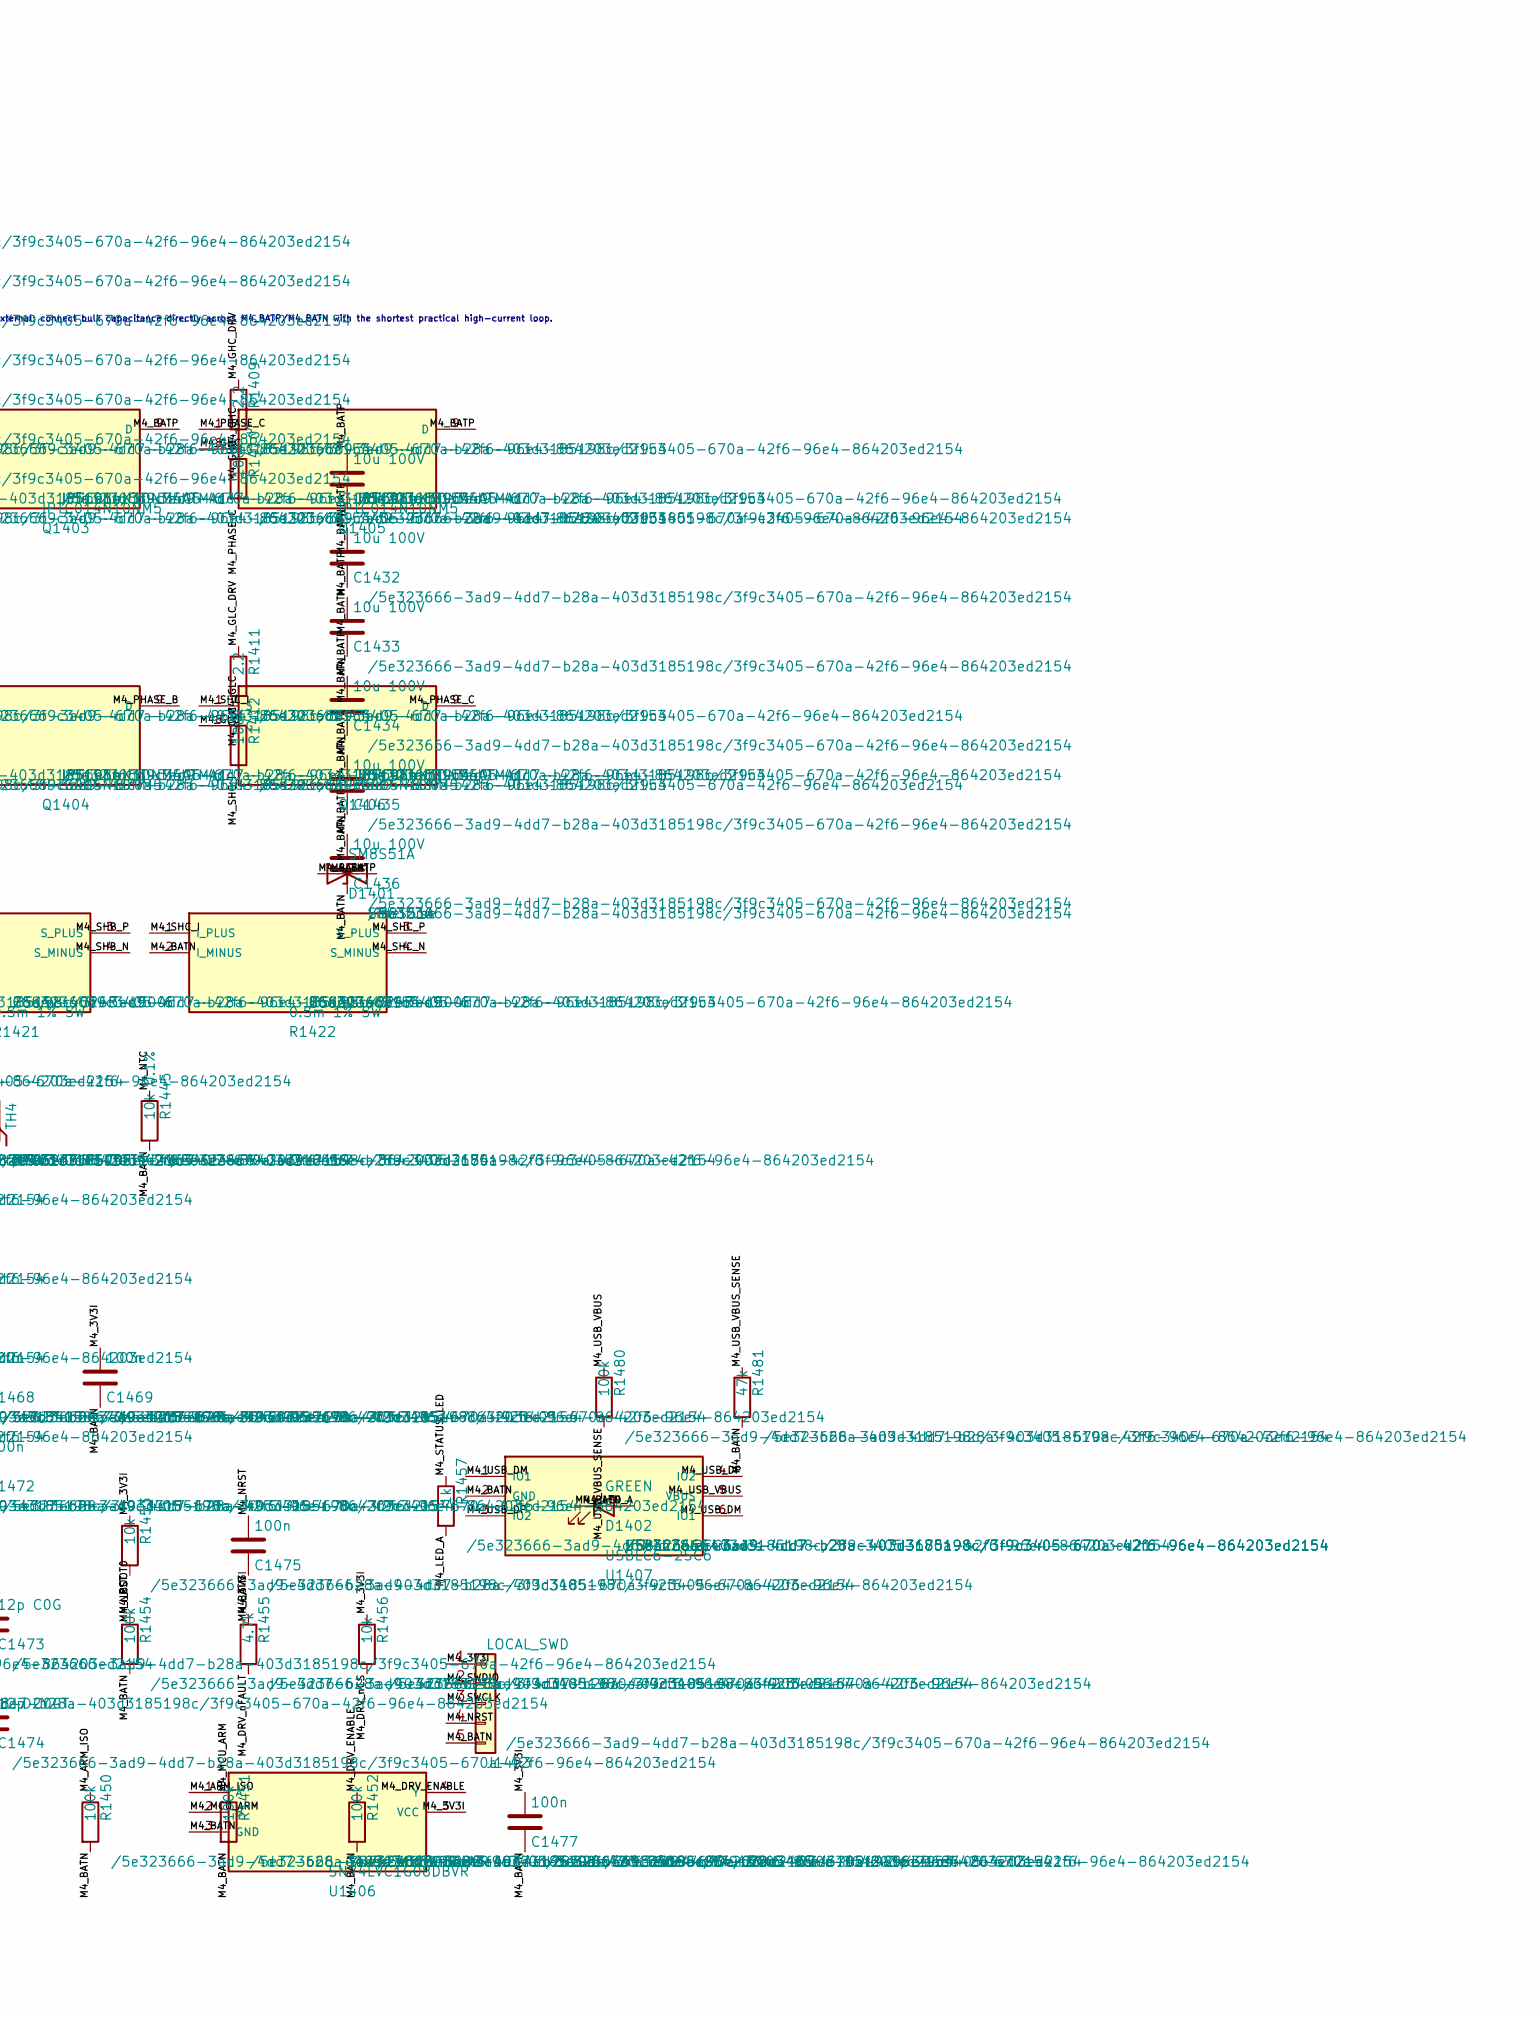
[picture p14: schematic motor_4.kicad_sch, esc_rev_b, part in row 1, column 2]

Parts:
C1401: 47n 100V; C_0603_1608Metric
C1402, C1403: 1u 16V; C_0603_1608Metric
C1404: 1u 10V; C_0603_1608Metric
C1405: 100n 100V; C_0603_1608Metric
C1406, C1431, C1432, C1433, C1434, C1435, C1436: 10u 100V; C_1210_3225Metric
C1407: 100n 10V; C_0603_1608Metric
C1420, C1421, C1422, C1423: 10n C0G; C_0603_1608Metric
C1450: 10n 50V; C_0603_1608Metric
C1460: 10u 10V; C_0805_2012Metric
C1461, C1464, C1465, C1475, C1476, C1477: 100n; C_0603_1608Metric
C1462, C1463: 2.2u 10V; C_0603_1608Metric
C1466: 4.7u; C_0603_1608Metric
C1467, C1468, C1469, C1470, C1472: 100n; C_0402_1005Metric
C1471: 1u; C_0603_1608Metric
C1473, C1474: 12p C0G; C_0402_1005Metric
D1401: SM8S51A; DO-218AB_SM8S; MPN SM8S51A
D1402: GREEN; LED_0603_1608Metric
FB1401: 600R@100MHz; L_0603_1608Metric; MPN BLM18AG601SN1D
J1401: FUSED_BATTERY_TAP; POWER_LUG_M5_2P_P20; MPN M5_RING_LUG_PAIR
J1402: MOTOR_PHASES; POWER_LUG_M5_3P_P20; MPN M5_RING_LUG_TRIPLE
J1403: LOCAL_SWD; PinHeader_1x05_P1.27mm_Vertical
PS1401: RFM-0505S; RFM_SIP4_11.5x6_P2.54; MPN RFM-0505S
Q1401, Q1402, Q1403, Q1404, Q1405, Q1406: IPTC014N10NM5; PG-HDSOP-16_TOLT_IPTC; MPN IPTC014N10NM5ATMA1
R1401, R1403, R1405, R1407, R1409, R1411: 2.2; R_0603_1608Metric
R1402, R1404, R1406, R1408, R1410, R1412, R1450, R1451, R1452, R1454, R1458, R1480: 100k; R_0603_1608Metric
R1420, R1421, R1422, R1423: 0.5m 1% 5W; CSS4J-4026_Kelvin; MPN CSS4J-4026R-L500F
R1430, R1431, R1432, R1433: 47; R_0603_1608Metric
R1440, R1441, R1442, R1443: 150k 0.1%; R_1206_3216Metric
R1444: 33k 0.1%; R_0603_1608Metric
R1445: 10k 0.1%; R_0603_1608Metric
R1453, R1456: 10k; R_0603_1608Metric
R1455: 4.7k; R_0603_1608Metric
R1457: 1k; R_0603_1608Metric
R1459: 68k; R_0603_1608Metric
R1481: 47k; R_0603_1608Metric
TH4: NTCG163JF103FT1; R_0603_1608Metric; MPN NTCG163JF103FT1
U1401: DRV8353SRTAR; WQFN-40-EP_6x6_P0.5; MPN DRV8353SRTAR
U1402: STM32G431CBT6; LQFP-48_7x7mm_P0.5mm; MPN STM32G431CBT6
U1403: ISO6731FDWR; SOIC-16W_7.5x10.3mm_P1.27mm; MPN ISO6731FDWR
U1404: TPS70933DBVR; SOT-23-5; MPN TPS70933DBVR
U1405: INA296A2IDR; SOIC-8_3.9x4.9mm_P1.27mm; MPN INA296A2IDR
U1406: SN74LVC1G08DBVR; SOT-23-5; MPN SN74LVC1G08DBVR
U1407: USBLC6-2SC6; SOT-23-6; MPN USBLC6-2SC6
Y1401: 8MHz ABM8G; Crystal_SMD_3225-4Pin_3.2x2.5mm; MPN ABM8G-8.000MHZ-18-D2Y-T

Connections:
/3V3: C1464.1, U1403.1 (V_{CC1}), U1403.7 (EN1); also elsewhere on the board
/5V: C1460.1, PS1401.2 (+VIN); also elsewhere on the board
/ARM_SAFE: U1403.4 (INB); also elsewhere on the board
/DGND: C1460.2, C1464.2, PS1401.1 (-VIN), U1403.2 (GND1), U1403.8 (GND1); also elsewhere on the board
/M4_BATN: C1403.2, C1404.2, C1405.2, C1406.2, C1407.2, C1420.2, C1421.2, C1422.2, C1423.2, C1431.2, C1432.2, C1433.2, C1434.2, C1435.2, C1436.2, C1450.2, C1461.2, C1462.2, C1463.2, C1465.2, C1466.2, C1467.2, C1468.2, C1469.2, C1470.2, C1471.2, C1472.2, C1473.2, C1474.2, C1475.2, C1476.2, C1477.2, D1401.1 (A1), D1402.1 (K), J1401.2, J1403.5, PS1401.3 (-VOUT), R1420.2 (I_MINUS), R1421.2 (I_MINUS), R1422.2 (I_MINUS), R1444.2, R1445.2, R1450.2, R1451.2, R1452.2, R1454.2, R1459.2, R1481.2, U1401.25 (AGND), U1401.39 (GND), U1401.41 (EP), U1402.19 (VSSA), U1402.23 (VSS), U1402.35 (VSS), U1402.47 (VSS), U1403.9 (GND2), U1403.15 (GND2), U1404.2 (GND), U1405.2 (GND), U1405.4 (NC), U1405.7 (REF1), U1406.3 (GND), U1407.2 (GND); also elsewhere on the board
/M4_BATP: C1402.2, C1405.1, C1406.1, C1431.1, C1432.1, C1433.1, C1434.1, C1435.1, C1436.1, D1401.2 (A2), Q1401.9 (D), Q1403.9 (D), Q1405.9 (D), R1423.2 (I_MINUS), R1440.1, U1401.3 (VM), U1401.4 (VDRAIN); also elsewhere on the board
/M4_CMD: U1403.3 (INA); also elsewhere on the board
/M4_PHASE_A: J1402.1, Q1401.1 (S), Q1402.9 (D), R1402.2, U1401.7 (SHA)
/M4_PHASE_B: J1402.2, Q1403.1 (S), Q1404.9 (D), R1406.2, U1401.14 (SHB)
/M4_PHASE_C: J1402.3, Q1405.1 (S), Q1406.9 (D), R1410.2, U1401.17 (SHC)
/M4_STATUS: U1403.5 (OUTC); also elsewhere on the board
/Motor 4 power cell/M4_3V3A: C1407.1, C1471.1, C1472.1, C1476.1, FB1401.2, TH4.1, U1401.24 (VREF), U1402.20 (VREF+), U1402.21 (VDDA), U1405.3 (REF2), U1405.6 (VS)
/Motor 4 power cell/M4_3V3I: C1463.1, C1465.1, C1466.1, C1467.1, C1468.1, C1469.1, C1470.1, C1477.1, FB1401.1, J1403.1, R1453.1, R1455.1, R1456.1, U1402.1 (VBAT), U1402.24 (VDD), U1402.36 (VDD), U1402.48 (VDD), U1403.10 (EN2), U1403.16 (V_{CC2}), U1404.5 (OUT), U1406.5 (VCC)
/Motor 4 power cell/M4_5VI: C1461.1, C1462.1, PS1401.4 (+VOUT), R1458.1, U1404.1 (IN)
/Motor 4 power cell/M4_ARM_ISO: R1450.1, U1402.25 (PB11), U1403.13 (OUTB), U1406.1 (A)
/Motor 4 power cell/M4_BATP_IN: J1401.1, R1423.1 (I_PLUS)
/Motor 4 power cell/M4_BOOT0: R1454.1, U1402.45 (PB8)
/Motor 4 power cell/M4_BUS: C1450.1, R1443.2, R1444.1, U1402.12 (PA4)
/Motor 4 power cell/M4_BUS_CURRENT: C1423.1, R1433.2, U1402.11 (PA3)
/Motor 4 power cell/M4_BUS_CURRENT_RAW: R1433.1, U1405.5 (OUT)
/Motor 4 power cell/M4_BUS_DIV_0: R1440.2, R1441.1
/Motor 4 power cell/M4_BUS_DIV_1: R1441.2, R1442.1
/Motor 4 power cell/M4_BUS_DIV_2: R1442.2, R1443.1
/Motor 4 power cell/M4_BUS_SH_N: R1423.4 (S_MINUS), U1405.1 (IN-)
/Motor 4 power cell/M4_BUS_SH_P: R1423.3 (S_PLUS), U1405.8 (IN+)
/Motor 4 power cell/M4_CPH: C1401.1, U1401.2 (CPH)
/Motor 4 power cell/M4_CPL: C1401.2, U1401.1 (CPL)
/Motor 4 power cell/M4_CSA_A: C1420.1, R1430.2, U1402.8 (PA0)
/Motor 4 power cell/M4_CSA_A_RAW: R1430.1, U1401.23 (SOA)
/Motor 4 power cell/M4_CSA_B: C1421.1, R1431.2, U1402.9 (PA1)
/Motor 4 power cell/M4_CSA_B_RAW: R1431.1, U1401.22 (SOB)
/Motor 4 power cell/M4_CSA_C: C1422.1, R1432.2, U1402.10 (PA2)
/Motor 4 power cell/M4_CSA_C_RAW: R1432.1, U1401.21 (SOC)
/Motor 4 power cell/M4_DRV_ENABLE: R1452.1, U1401.31 (ENABLE), U1406.4 (Y)
/Motor 4 power cell/M4_DRV_SCLK: U1401.29 (SCLK), U1402.13 (PA5)
/Motor 4 power cell/M4_DRV_SDI: U1401.28 (SDI), U1402.15 (PA7)
/Motor 4 power cell/M4_DRV_SDO: U1401.27 (SDO), U1402.14 (PA6)
/Motor 4 power cell/M4_DRV_nCS: R1456.2, U1401.30 (nSCS), U1402.26 (PB12)
/Motor 4 power cell/M4_DRV_nFAULT: R1455.2, U1401.26 (nFAULT), U1402.22 (PB10)
/Motor 4 power cell/M4_DVDD: C1404.1, U1401.38 (DVDD)
/Motor 4 power cell/M4_GHA: Q1401.8 (G), R1401.2, R1402.1
/Motor 4 power cell/M4_GHA_DRV: R1401.1, U1401.6 (GHA)
/Motor 4 power cell/M4_GHB: Q1403.8 (G), R1405.2, R1406.1
/Motor 4 power cell/M4_GHB_DRV: R1405.1, U1401.15 (GHB)
/Motor 4 power cell/M4_GHC: Q1405.8 (G), R1409.2, R1410.1
/Motor 4 power cell/M4_GHC_DRV: R1409.1, U1401.16 (GHC)
/Motor 4 power cell/M4_GLA: Q1402.8 (G), R1403.2, R1404.1
/Motor 4 power cell/M4_GLA_DRV: R1403.1, U1401.8 (GLA)
/Motor 4 power cell/M4_GLB: Q1404.8 (G), R1407.2, R1408.1
/Motor 4 power cell/M4_GLB_DRV: R1407.1, U1401.13 (GLB)
/Motor 4 power cell/M4_GLC: Q1406.8 (G), R1411.2, R1412.1
/Motor 4 power cell/M4_GLC_DRV: R1411.1, U1401.18 (GLC)
/Motor 4 power cell/M4_LDO_EN: R1458.2, R1459.1, U1404.3 (EN)
/Motor 4 power cell/M4_LED_A: D1402.2 (A), R1457.2
/Motor 4 power cell/M4_MCU_ARM: R1451.1, U1402.41 (PB4), U1406.2 (B)
/Motor 4 power cell/M4_NRST: C1475.1, J1403.4, R1453.2, U1402.7 (PG10)
/Motor 4 power cell/M4_NTC: R1445.1, TH4.2, U1402.16 (PB0)
/Motor 4 power cell/M4_OSC_IN: C1473.1, U1402.5 (PF0), Y1401.1
/Motor 4 power cell/M4_OSC_OUT: C1474.1, U1402.6 (PF1), Y1401.2
/Motor 4 power cell/M4_PWM_AH: U1401.32 (INHA), U1402.30 (PA8)
/Motor 4 power cell/M4_PWM_AL: U1401.33 (INLA), U1402.27 (PB13)
/Motor 4 power cell/M4_PWM_BH: U1401.34 (INHB), U1402.31 (PA9)
/Motor 4 power cell/M4_PWM_BL: U1401.35 (INLB), U1402.28 (PB14)
/Motor 4 power cell/M4_PWM_CH: U1401.36 (INHC), U1402.32 (PA10)
/Motor 4 power cell/M4_PWM_CL: U1401.37 (INLC), U1402.29 (PB15)
/Motor 4 power cell/M4_SHA_I: Q1402.1 (S), R1404.2, R1420.1 (I_PLUS)
/Motor 4 power cell/M4_SHA_N: R1420.4 (S_MINUS), U1401.10 (SNA)
/Motor 4 power cell/M4_SHA_P: R1420.3 (S_PLUS), U1401.9 (SPA)
/Motor 4 power cell/M4_SHB_I: Q1404.1 (S), R1408.2, R1421.1 (I_PLUS)
/Motor 4 power cell/M4_SHB_N: R1421.4 (S_MINUS), U1401.11 (SNB)
/Motor 4 power cell/M4_SHB_P: R1421.3 (S_PLUS), U1401.12 (SPB)
/Motor 4 power cell/M4_SHC_I: Q1406.1 (S), R1412.2, R1422.1 (I_PLUS)
/Motor 4 power cell/M4_SHC_N: R1422.4 (S_MINUS), U1401.20 (SNC)
/Motor 4 power cell/M4_SHC_P: R1422.3 (S_PLUS), U1401.19 (SPC)
/Motor 4 power cell/M4_STATUS_LED: R1457.1, U1402.42 (PB5)
/Motor 4 power cell/M4_SWCLK: J1403.3, U1402.38 (PA14)
/Motor 4 power cell/M4_SWDIO: J1403.2, U1402.37 (PA13)
/Motor 4 power cell/M4_UART_RX: U1402.44 (PB7), U1403.14 (OUTA)
/Motor 4 power cell/M4_UART_TX: U1402.43 (PB6), U1403.12 (INC)
/Motor 4 power cell/M4_USB_DM: U1402.33 (PA11), U1407.1 (IO1), U1407.6 (IO1)
/Motor 4 power cell/M4_USB_DP: U1402.34 (PA12), U1407.3 (IO2), U1407.4 (IO2)
/Motor 4 power cell/M4_USB_VBUS: R1480.1, U1407.5 (VBUS)
/Motor 4 power cell/M4_USB_VBUS_SENSE: R1480.2, R1481.1
/Motor 4 power cell/M4_VCP: C1402.1, U1401.5 (VCP)
/Motor 4 power cell/M4_VGLS: C1403.1, U1401.40 (VGLS)

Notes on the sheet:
MOTOR 4: 12S / 60 A CONTINUOUS CELL Local STM32G431: 3 leg shunts + DC-input shunt, sampled every PWM cycle. Command/arm/status are isolated; DGND never bonds to this cell's BATN.
C1430 is external: connect bulk capacitance directly across M4_BATP/M4_BATN with the shortest practical high-current loop.

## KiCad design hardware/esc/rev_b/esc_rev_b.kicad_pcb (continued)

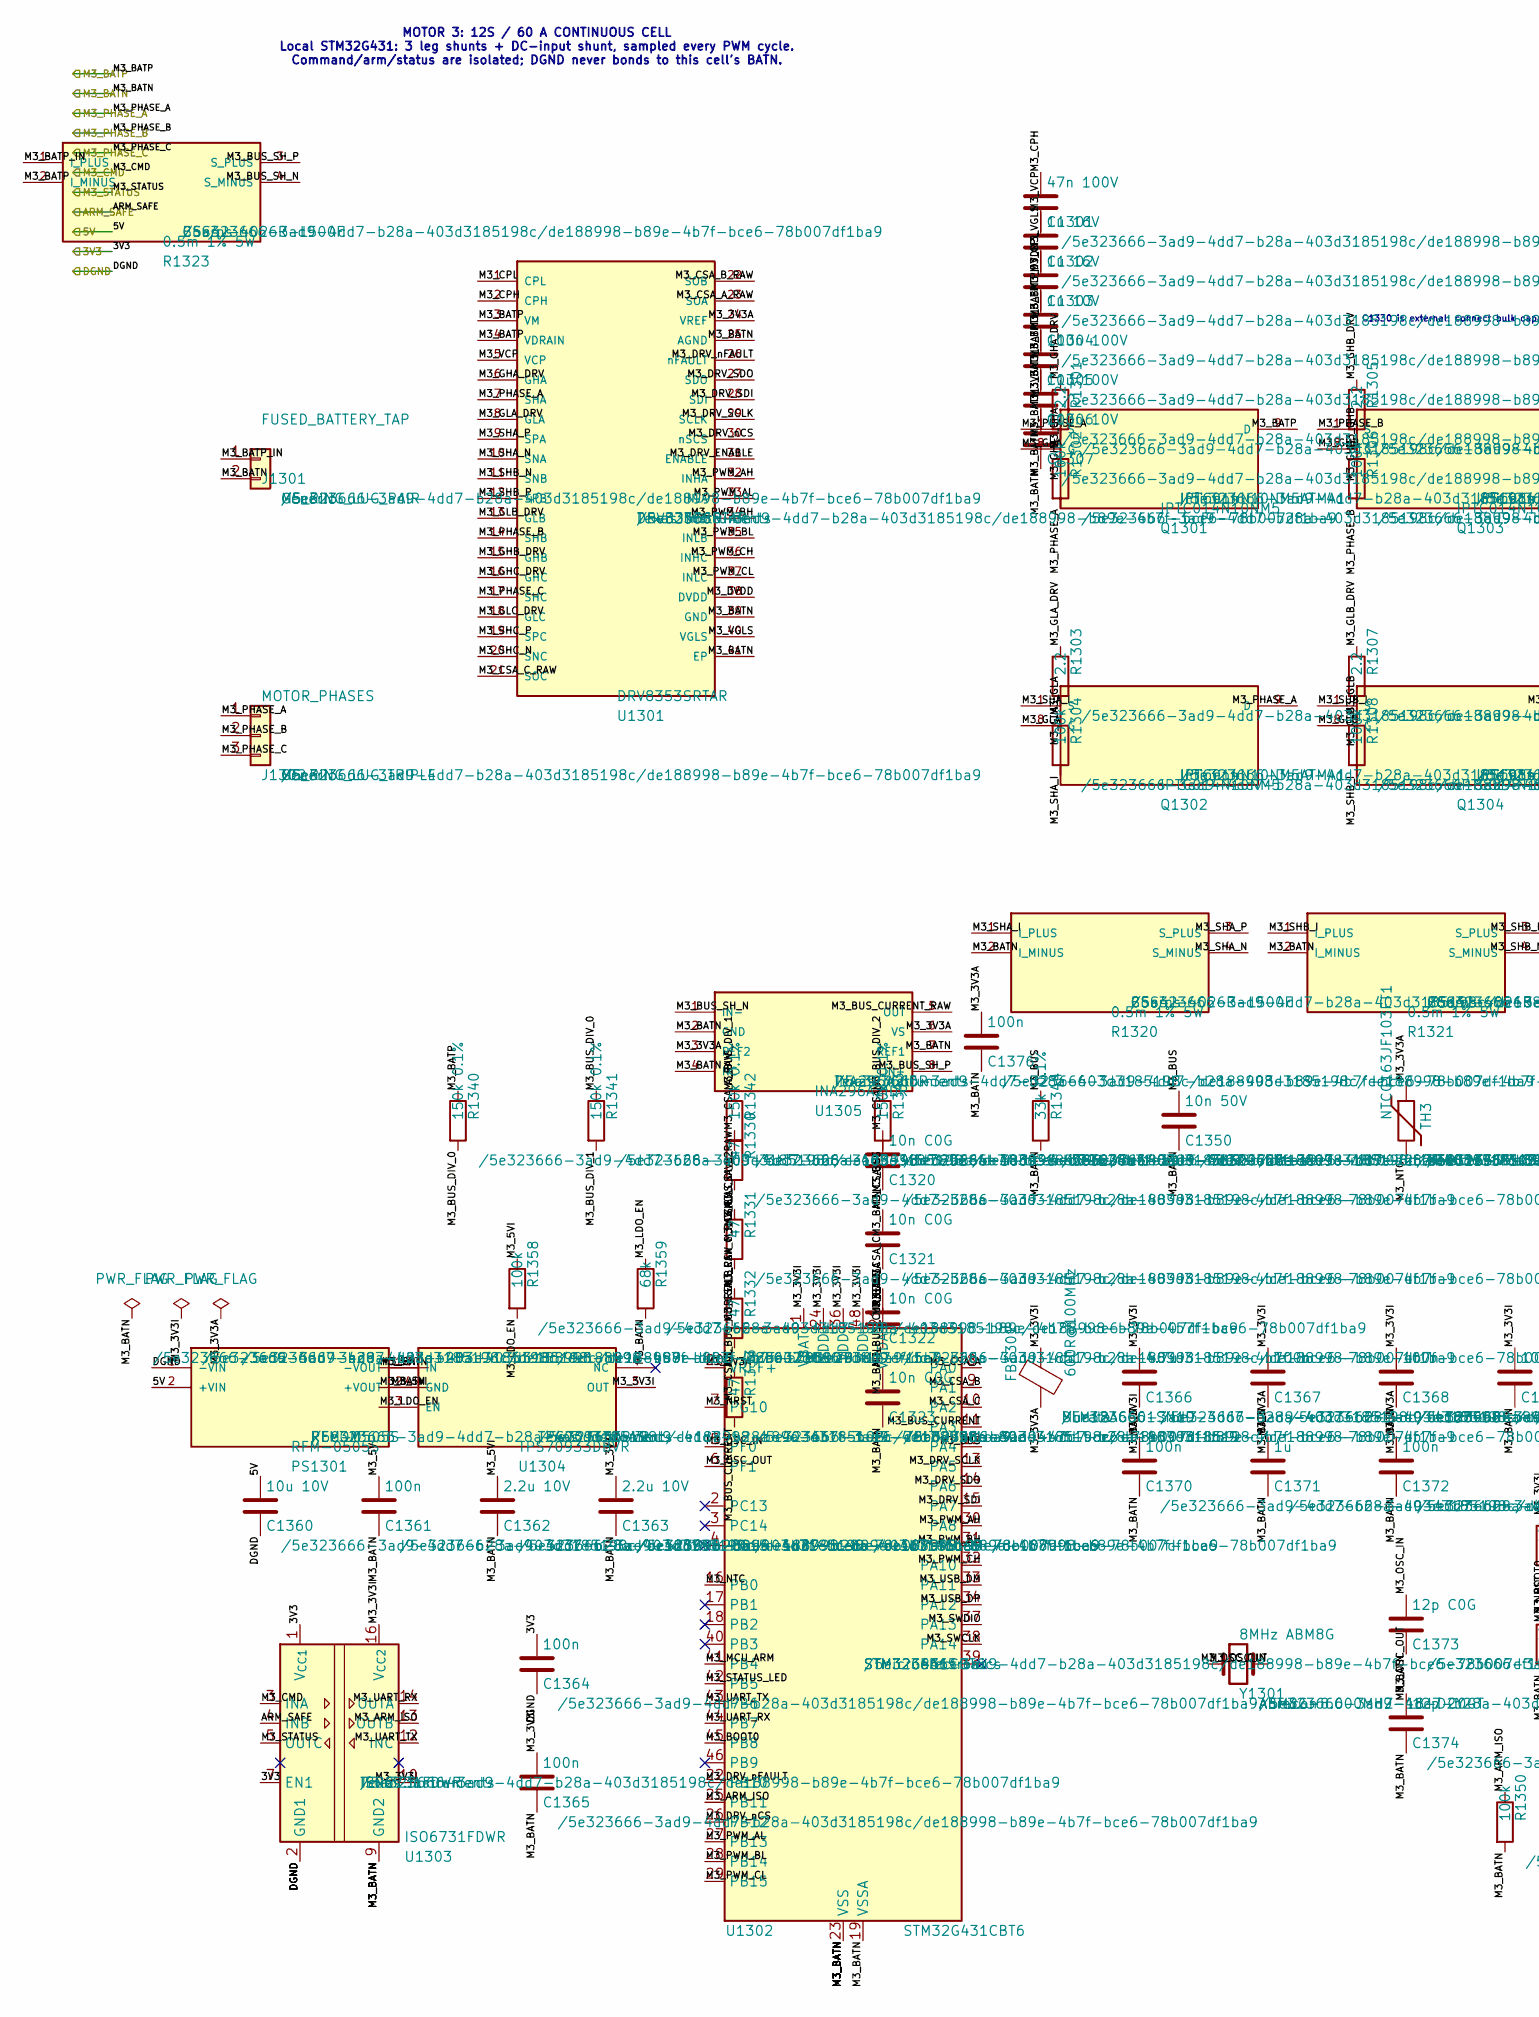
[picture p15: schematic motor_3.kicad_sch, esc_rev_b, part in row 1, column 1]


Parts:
C1301: 47n 100V; C_0603_1608Metric
C1302, C1303: 1u 16V; C_0603_1608Metric
C1304: 1u 10V; C_0603_1608Metric
C1305: 100n 100V; C_0603_1608Metric
C1306, C1331, C1332, C1333, C1334, C1335, C1336: 10u 100V; C_1210_3225Metric
C1307: 100n 10V; C_0603_1608Metric
C1320, C1321, C1322, C1323: 10n C0G; C_0603_1608Metric
C1350: 10n 50V; C_0603_1608Metric
C1360: 10u 10V; C_0805_2012Metric
C1361, C1364, C1365, C1375, C1376, C1377: 100n; C_0603_1608Metric
C1362, C1363: 2.2u 10V; C_0603_1608Metric
C1366: 4.7u; C_0603_1608Metric
C1367, C1368, C1369, C1370, C1372: 100n; C_0402_1005Metric
C1371: 1u; C_0603_1608Metric
C1373, C1374: 12p C0G; C_0402_1005Metric
D1301: SM8S51A; DO-218AB_SM8S; MPN SM8S51A
D1302: GREEN; LED_0603_1608Metric
FB1301: 600R@100MHz; L_0603_1608Metric; MPN BLM18AG601SN1D
J1301: FUSED_BATTERY_TAP; POWER_LUG_M5_2P_P20; MPN M5_RING_LUG_PAIR
J1302: MOTOR_PHASES; POWER_LUG_M5_3P_P20; MPN M5_RING_LUG_TRIPLE
J1303: LOCAL_SWD; PinHeader_1x05_P1.27mm_Vertical
PS1301: RFM-0505S; RFM_SIP4_11.5x6_P2.54; MPN RFM-0505S
Q1301, Q1302, Q1303, Q1304, Q1305, Q1306: IPTC014N10NM5; PG-HDSOP-16_TOLT_IPTC; MPN IPTC014N10NM5ATMA1
R1301, R1303, R1305, R1307, R1309, R1311: 2.2; R_0603_1608Metric
R1302, R1304, R1306, R1308, R1310, R1312, R1350, R1351, R1352, R1354, R1358, R1380: 100k; R_0603_1608Metric
R1320, R1321, R1322, R1323: 0.5m 1% 5W; CSS4J-4026_Kelvin; MPN CSS4J-4026R-L500F
R1330, R1331, R1332, R1333: 47; R_0603_1608Metric
R1340, R1341, R1342, R1343: 150k 0.1%; R_1206_3216Metric
R1344: 33k 0.1%; R_0603_1608Metric
R1345: 10k 0.1%; R_0603_1608Metric
R1353, R1356: 10k; R_0603_1608Metric
R1355: 4.7k; R_0603_1608Metric
R1357: 1k; R_0603_1608Metric
R1359: 68k; R_0603_1608Metric
R1381: 47k; R_0603_1608Metric
TH3: NTCG163JF103FT1; R_0603_1608Metric; MPN NTCG163JF103FT1
U1301: DRV8353SRTAR; WQFN-40-EP_6x6_P0.5; MPN DRV8353SRTAR
U1302: STM32G431CBT6; LQFP-48_7x7mm_P0.5mm; MPN STM32G431CBT6
U1303: ISO6731FDWR; SOIC-16W_7.5x10.3mm_P1.27mm; MPN ISO6731FDWR
U1304: TPS70933DBVR; SOT-23-5; MPN TPS70933DBVR
U1305: INA296A2IDR; SOIC-8_3.9x4.9mm_P1.27mm; MPN INA296A2IDR
U1306: SN74LVC1G08DBVR; SOT-23-5; MPN SN74LVC1G08DBVR
U1307: USBLC6-2SC6; SOT-23-6; MPN USBLC6-2SC6
Y1301: 8MHz ABM8G; Crystal_SMD_3225-4Pin_3.2x2.5mm; MPN ABM8G-8.000MHZ-18-D2Y-T

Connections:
/3V3: C1364.1, U1303.1 (V_{CC1}), U1303.7 (EN1); also elsewhere on the board
/5V: C1360.1, PS1301.2 (+VIN); also elsewhere on the board
/ARM_SAFE: U1303.4 (INB); also elsewhere on the board
/DGND: C1360.2, C1364.2, PS1301.1 (-VIN), U1303.2 (GND1), U1303.8 (GND1); also elsewhere on the board
/M3_BATN: C1303.2, C1304.2, C1305.2, C1306.2, C1307.2, C1320.2, C1321.2, C1322.2, C1323.2, C1331.2, C1332.2, C1333.2, C1334.2, C1335.2, C1336.2, C1350.2, C1361.2, C1362.2, C1363.2, C1365.2, C1366.2, C1367.2, C1368.2, C1369.2, C1370.2, C1371.2, C1372.2, C1373.2, C1374.2, C1375.2, C1376.2, C1377.2, D1301.1 (A1), D1302.1 (K), J1301.2, J1303.5, PS1301.3 (-VOUT), R1320.2 (I_MINUS), R1321.2 (I_MINUS), R1322.2 (I_MINUS), R1344.2, R1345.2, R1350.2, R1351.2, R1352.2, R1354.2, R1359.2, R1381.2, U1301.25 (AGND), U1301.39 (GND), U1301.41 (EP), U1302.19 (VSSA), U1302.23 (VSS), U1302.35 (VSS), U1302.47 (VSS), U1303.9 (GND2), U1303.15 (GND2), U1304.2 (GND), U1305.2 (GND), U1305.4 (NC), U1305.7 (REF1), U1306.3 (GND), U1307.2 (GND); also elsewhere on the board
/M3_BATP: C1302.2, C1305.1, C1306.1, C1331.1, C1332.1, C1333.1, C1334.1, C1335.1, C1336.1, D1301.2 (A2), Q1301.9 (D), Q1303.9 (D), Q1305.9 (D), R1323.2 (I_MINUS), R1340.1, U1301.3 (VM), U1301.4 (VDRAIN); also elsewhere on the board
/M3_CMD: U1303.3 (INA); also elsewhere on the board
/M3_PHASE_A: J1302.1, Q1301.1 (S), Q1302.9 (D), R1302.2, U1301.7 (SHA)
/M3_PHASE_B: J1302.2, Q1303.1 (S), Q1304.9 (D), R1306.2, U1301.14 (SHB)
/M3_PHASE_C: J1302.3, Q1305.1 (S), Q1306.9 (D), R1310.2, U1301.17 (SHC)
/M3_STATUS: U1303.5 (OUTC); also elsewhere on the board
/Motor 3 power cell/M3_3V3A: C1307.1, C1371.1, C1372.1, C1376.1, FB1301.2, TH3.1, U1301.24 (VREF), U1302.20 (VREF+), U1302.21 (VDDA), U1305.3 (REF2), U1305.6 (VS)
/Motor 3 power cell/M3_3V3I: C1363.1, C1365.1, C1366.1, C1367.1, C1368.1, C1369.1, C1370.1, C1377.1, FB1301.1, J1303.1, R1353.1, R1355.1, R1356.1, U1302.1 (VBAT), U1302.24 (VDD), U1302.36 (VDD), U1302.48 (VDD), U1303.10 (EN2), U1303.16 (V_{CC2}), U1304.5 (OUT), U1306.5 (VCC)
/Motor 3 power cell/M3_5VI: C1361.1, C1362.1, PS1301.4 (+VOUT), R1358.1, U1304.1 (IN)
/Motor 3 power cell/M3_ARM_ISO: R1350.1, U1302.25 (PB11), U1303.13 (OUTB), U1306.1 (A)
/Motor 3 power cell/M3_BATP_IN: J1301.1, R1323.1 (I_PLUS)
/Motor 3 power cell/M3_BOOT0: R1354.1, U1302.45 (PB8)
/Motor 3 power cell/M3_BUS: C1350.1, R1343.2, R1344.1, U1302.12 (PA4)
/Motor 3 power cell/M3_BUS_CURRENT: C1323.1, R1333.2, U1302.11 (PA3)
/Motor 3 power cell/M3_BUS_CURRENT_RAW: R1333.1, U1305.5 (OUT)
/Motor 3 power cell/M3_BUS_DIV_0: R1340.2, R1341.1
/Motor 3 power cell/M3_BUS_DIV_1: R1341.2, R1342.1
/Motor 3 power cell/M3_BUS_DIV_2: R1342.2, R1343.1
/Motor 3 power cell/M3_BUS_SH_N: R1323.4 (S_MINUS), U1305.1 (IN-)
/Motor 3 power cell/M3_BUS_SH_P: R1323.3 (S_PLUS), U1305.8 (IN+)
/Motor 3 power cell/M3_CPH: C1301.1, U1301.2 (CPH)
/Motor 3 power cell/M3_CPL: C1301.2, U1301.1 (CPL)
/Motor 3 power cell/M3_CSA_A: C1320.1, R1330.2, U1302.8 (PA0)
/Motor 3 power cell/M3_CSA_A_RAW: R1330.1, U1301.23 (SOA)
/Motor 3 power cell/M3_CSA_B: C1321.1, R1331.2, U1302.9 (PA1)
/Motor 3 power cell/M3_CSA_B_RAW: R1331.1, U1301.22 (SOB)
/Motor 3 power cell/M3_CSA_C: C1322.1, R1332.2, U1302.10 (PA2)
/Motor 3 power cell/M3_CSA_C_RAW: R1332.1, U1301.21 (SOC)
/Motor 3 power cell/M3_DRV_ENABLE: R1352.1, U1301.31 (ENABLE), U1306.4 (Y)
/Motor 3 power cell/M3_DRV_SCLK: U1301.29 (SCLK), U1302.13 (PA5)
/Motor 3 power cell/M3_DRV_SDI: U1301.28 (SDI), U1302.15 (PA7)
/Motor 3 power cell/M3_DRV_SDO: U1301.27 (SDO), U1302.14 (PA6)
/Motor 3 power cell/M3_DRV_nCS: R1356.2, U1301.30 (nSCS), U1302.26 (PB12)
/Motor 3 power cell/M3_DRV_nFAULT: R1355.2, U1301.26 (nFAULT), U1302.22 (PB10)
/Motor 3 power cell/M3_DVDD: C1304.1, U1301.38 (DVDD)
/Motor 3 power cell/M3_GHA: Q1301.8 (G), R1301.2, R1302.1
/Motor 3 power cell/M3_GHA_DRV: R1301.1, U1301.6 (GHA)
/Motor 3 power cell/M3_GHB: Q1303.8 (G), R1305.2, R1306.1
/Motor 3 power cell/M3_GHB_DRV: R1305.1, U1301.15 (GHB)
/Motor 3 power cell/M3_GHC: Q1305.8 (G), R1309.2, R1310.1
/Motor 3 power cell/M3_GHC_DRV: R1309.1, U1301.16 (GHC)
/Motor 3 power cell/M3_GLA: Q1302.8 (G), R1303.2, R1304.1
/Motor 3 power cell/M3_GLA_DRV: R1303.1, U1301.8 (GLA)
/Motor 3 power cell/M3_GLB: Q1304.8 (G), R1307.2, R1308.1
/Motor 3 power cell/M3_GLB_DRV: R1307.1, U1301.13 (GLB)
/Motor 3 power cell/M3_GLC: Q1306.8 (G), R1311.2, R1312.1
/Motor 3 power cell/M3_GLC_DRV: R1311.1, U1301.18 (GLC)
/Motor 3 power cell/M3_LDO_EN: R1358.2, R1359.1, U1304.3 (EN)
/Motor 3 power cell/M3_LED_A: D1302.2 (A), R1357.2
/Motor 3 power cell/M3_MCU_ARM: R1351.1, U1302.41 (PB4), U1306.2 (B)
/Motor 3 power cell/M3_NRST: C1375.1, J1303.4, R1353.2, U1302.7 (PG10)
/Motor 3 power cell/M3_NTC: R1345.1, TH3.2, U1302.16 (PB0)
/Motor 3 power cell/M3_OSC_IN: C1373.1, U1302.5 (PF0), Y1301.1
/Motor 3 power cell/M3_OSC_OUT: C1374.1, U1302.6 (PF1), Y1301.2
/Motor 3 power cell/M3_PWM_AH: U1301.32 (INHA), U1302.30 (PA8)
/Motor 3 power cell/M3_PWM_AL: U1301.33 (INLA), U1302.27 (PB13)
/Motor 3 power cell/M3_PWM_BH: U1301.34 (INHB), U1302.31 (PA9)
/Motor 3 power cell/M3_PWM_BL: U1301.35 (INLB), U1302.28 (PB14)
/Motor 3 power cell/M3_PWM_CH: U1301.36 (INHC), U1302.32 (PA10)
/Motor 3 power cell/M3_PWM_CL: U1301.37 (INLC), U1302.29 (PB15)
/Motor 3 power cell/M3_SHA_I: Q1302.1 (S), R1304.2, R1320.1 (I_PLUS)
/Motor 3 power cell/M3_SHA_N: R1320.4 (S_MINUS), U1301.10 (SNA)
/Motor 3 power cell/M3_SHA_P: R1320.3 (S_PLUS), U1301.9 (SPA)
/Motor 3 power cell/M3_SHB_I: Q1304.1 (S), R1308.2, R1321.1 (I_PLUS)
/Motor 3 power cell/M3_SHB_N: R1321.4 (S_MINUS), U1301.11 (SNB)
/Motor 3 power cell/M3_SHB_P: R1321.3 (S_PLUS), U1301.12 (SPB)
/Motor 3 power cell/M3_SHC_I: Q1306.1 (S), R1312.2, R1322.1 (I_PLUS)
/Motor 3 power cell/M3_SHC_N: R1322.4 (S_MINUS), U1301.20 (SNC)
/Motor 3 power cell/M3_SHC_P: R1322.3 (S_PLUS), U1301.19 (SPC)
/Motor 3 power cell/M3_STATUS_LED: R1357.1, U1302.42 (PB5)
/Motor 3 power cell/M3_SWCLK: J1303.3, U1302.38 (PA14)
/Motor 3 power cell/M3_SWDIO: J1303.2, U1302.37 (PA13)
/Motor 3 power cell/M3_UART_RX: U1302.44 (PB7), U1303.14 (OUTA)
/Motor 3 power cell/M3_UART_TX: U1302.43 (PB6), U1303.12 (INC)
/Motor 3 power cell/M3_USB_DM: U1302.33 (PA11), U1307.1 (IO1), U1307.6 (IO1)
/Motor 3 power cell/M3_USB_DP: U1302.34 (PA12), U1307.3 (IO2), U1307.4 (IO2)
/Motor 3 power cell/M3_USB_VBUS: R1380.1, U1307.5 (VBUS)
/Motor 3 power cell/M3_USB_VBUS_SENSE: R1380.2, R1381.1
/Motor 3 power cell/M3_VCP: C1302.1, U1301.5 (VCP)
/Motor 3 power cell/M3_VGLS: C1303.1, U1301.40 (VGLS)

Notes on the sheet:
MOTOR 3: 12S / 60 A CONTINUOUS CELL Local STM32G431: 3 leg shunts + DC-input shunt, sampled every PWM cycle. Command/arm/status are isolated; DGND never bonds to this cell's BATN.
C1330 is external: connect bulk capacitance directly across M3_BATP/M3_BATN with the shortest practical high-current loop.



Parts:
C700, C701, C710: 2.2u 100V X7R; C_1210_3225Metric
C702, C711: 10u 100V; C_1210_3225Metric
C703, C712: 2.2n 50V X7R; C_0603_1608Metric
C704, C705, C713, C714: 22u 10V; C_1210_3225Metric
C706, C707: 1u; C_0603_1608Metric
C708, C715: 3.3n X7R; C_0603_1608Metric
C709, C716: 470p C0G; C_0603_1608Metric
D701: SM8S51A; DO-218AB_SM8S; MPN SM8S51A
F701: PTC 0.75A; Fuse_1206_3216Metric; MPN 1206L075/24WR
J701: AUX_BATTERY; Molex_Micro-Fit_3.0_43650-0200_1x02_P3.00mm_Horizontal; MPN 43650-0200
J702: FLIGHT_CAN_POWER; JST_GH_SM04B-GHS-TB_1x04-1MP_P1.25mm_Horizontal; MPN SM04B-GHS-TB
L701, L702: 33u 1.8A; L_Bourns_SRR1260
R701, R710: 41.2k 1%; R_0603_1608Metric
R702, R711: 45.3k 1%; R_0603_1608Metric
R703, R712: 14.3k 1%; R_0603_1608Metric
R704: 0 STAR; R_1206_3216Metric
R705, R713: 226k 1%; R_0603_1608Metric
U701, U703: LM5164DDA; HSOP-8-1EP_3.9x4.9mm_P1.27mm_EP2.41x3.1mm_ThermalVias; MPN LM5164DDAR
U702: AP2112K-3.3TRG1; SOT-23-5; MPN AP2112K-3.3TRG1

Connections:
/3V3: C707.1, U702.5 (VOUT); also elsewhere on the board
/5V: C704.1, C705.1, C706.1, C708.2, L701.2, R702.1, U702.1 (VIN), U702.3 (EN); also elsewhere on the board
/AUX_BATT: C700.1, C701.1, C702.1, C710.1, C711.1, D701.2 (A2), J701.1, U701.2 (VIN), U701.3 (EN/UVLO), U703.2 (VIN), U703.3 (EN/UVLO)
/AUX_GND: C700.2, C701.2, C702.2, C704.2, C705.2, C710.2, C711.2, C713.2, C714.2, D701.1 (A1), J701.2, R701.2, R703.2, R704.1, R710.2, R712.2, U701.1 (GND), U701.9 (EP), U703.1 (GND), U703.9 (EP)
/Auxiliary power/CAN_5V_OUT: F701.2, J702.1
/Auxiliary power/CAN_5V_RAW: C713.1, C714.1, C715.2, F701.1, L702.2, R711.1
/Auxiliary power/LM2_BST: C712.1, U703.7 (BST)
/Auxiliary power/LM2_FB: C716.2, R711.2, R712.1, U703.5 (FB)
/Auxiliary power/LM2_RIPPLE: C715.1, C716.1, R713.2
/Auxiliary power/LM2_RON: R710.1, U703.4 (RON)
/Auxiliary power/LM2_SW: C712.2, L702.1, R713.1, U703.8 (SW)
/Auxiliary power/LM_BST: C703.1, U701.7 (BST)
/Auxiliary power/LM_FB: C709.2, R702.2, R703.1, U701.5 (FB)
/Auxiliary power/LM_RIPPLE: C708.1, C709.1, R705.2
/Auxiliary power/LM_RON: R701.1, U701.4 (RON)
/Auxiliary power/LM_SW: C703.2, L701.1, R705.1, U701.8 (SW)
/CANH: J702.3; also elsewhere on the board
/CANL: J702.4; also elsewhere on the board
/DGND: C706.2, C707.2, J702.2, R704.2, U702.2 (GND); also elsewhere on the board

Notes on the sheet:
TWO INDEPENDENT 1 A AUXILIARY RAILS One LM5164 powers ESC logic/cells; the other powers the flight board over CAN. The fused auxiliary input never carries motor current.

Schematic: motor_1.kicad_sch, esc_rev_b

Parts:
C1101: 47n 100V; C_0603_1608Metric
C1102, C1103: 1u 16V; C_0603_1608Metric
C1104: 1u 10V; C_0603_1608Metric
C1105: 100n 100V; C_0603_1608Metric
C1106, C1131, C1132, C1133, C1134, C1135, C1136: 10u 100V; C_1210_3225Metric
C1107: 100n 10V; C_0603_1608Metric
C1120, C1121, C1122, C1123: 10n C0G; C_0603_1608Metric
C1150: 10n 50V; C_0603_1608Metric
C1160: 10u 10V; C_0805_2012Metric
C1161, C1164, C1165, C1175, C1176, C1177: 100n; C_0603_1608Metric
C1162, C1163: 2.2u 10V; C_0603_1608Metric
C1166: 4.7u; C_0603_1608Metric
C1167, C1168, C1169, C1170, C1172: 100n; C_0402_1005Metric
C1171: 1u; C_0603_1608Metric
C1173, C1174: 12p C0G; C_0402_1005Metric
D1101: SM8S51A; DO-218AB_SM8S; MPN SM8S51A
D1102: GREEN; LED_0603_1608Metric
FB1101: 600R@100MHz; L_0603_1608Metric; MPN BLM18AG601SN1D
J1101: FUSED_BATTERY_TAP; POWER_LUG_M5_2P_P20; MPN M5_RING_LUG_PAIR
J1102: MOTOR_PHASES; POWER_LUG_M5_3P_P20; MPN M5_RING_LUG_TRIPLE
J1103: LOCAL_SWD; PinHeader_1x05_P1.27mm_Vertical
PS1101: RFM-0505S; RFM_SIP4_11.5x6_P2.54; MPN RFM-0505S
Q1101, Q1102, Q1103, Q1104, Q1105, Q1106: IPTC014N10NM5; PG-HDSOP-16_TOLT_IPTC; MPN IPTC014N10NM5ATMA1
R1101, R1103, R1105, R1107, R1109, R1111: 2.2; R_0603_1608Metric
R1102, R1104, R1106, R1108, R1110, R1112, R1150, R1151, R1152, R1154, R1158, R1180: 100k; R_0603_1608Metric
R1120, R1121, R1122, R1123: 0.5m 1% 5W; CSS4J-4026_Kelvin; MPN CSS4J-4026R-L500F
R1130, R1131, R1132, R1133: 47; R_0603_1608Metric
R1140, R1141, R1142, R1143: 150k 0.1%; R_1206_3216Metric
R1144: 33k 0.1%; R_0603_1608Metric
R1145: 10k 0.1%; R_0603_1608Metric
R1153, R1156: 10k; R_0603_1608Metric
R1155: 4.7k; R_0603_1608Metric
R1157: 1k; R_0603_1608Metric
R1159: 68k; R_0603_1608Metric
R1181: 47k; R_0603_1608Metric
TH1: NTCG163JF103FT1; R_0603_1608Metric; MPN NTCG163JF103FT1
U1101: DRV8353SRTAR; WQFN-40-EP_6x6_P0.5; MPN DRV8353SRTAR
U1102: STM32G431CBT6; LQFP-48_7x7mm_P0.5mm; MPN STM32G431CBT6
U1103: ISO6731FDWR; SOIC-16W_7.5x10.3mm_P1.27mm; MPN ISO6731FDWR
U1104: TPS70933DBVR; SOT-23-5; MPN TPS70933DBVR
U1105: INA296A2IDR; SOIC-8_3.9x4.9mm_P1.27mm; MPN INA296A2IDR
U1106: SN74LVC1G08DBVR; SOT-23-5; MPN SN74LVC1G08DBVR
U1107: USBLC6-2SC6; SOT-23-6; MPN USBLC6-2SC6
Y1101: 8MHz ABM8G; Crystal_SMD_3225-4Pin_3.2x2.5mm; MPN ABM8G-8.000MHZ-18-D2Y-T
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

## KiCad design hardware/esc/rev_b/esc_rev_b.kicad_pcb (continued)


Board: 4 copper layers, 173.8 x 282.9 mm, 687 parts (0 on the bottom side), 556 nets.

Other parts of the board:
C234, C235: 1n 2kV; C_1206_3216Metric
C1130, C1230, C1330, C1430, C1530, C1630: 820u 100V; CP_Radial_D18.0mm_P7.50mm
J202: CTRL_USB_C; USB_C_Receptacle_GCT_USB4105-xx-A_16P_TopMnt_Horizontal
J203: MOTOR_DFU_USB_C; USB_C_Receptacle_GCT_USB4105-xx-A_16P_TopMnt_Horizontal
R204, R205, R211, R212: 5.1k; R_0603_1608Metric
R206, R207: 27; R_0402_1005Metric
R208: 100k; R_0603_1608Metric
R209: 47k; R_0603_1608Metric
R210, R213: 1M; R_0603_1608Metric
R214, R215, R216, R217, R218, R219: 10k; R_0603_1608Metric
SW201: 6-WAY ACTIVE-LOW SELECTOR; PinHeader_1x07_P2.54mm_Vertical
U208, U209: USBLC6-2SC6; SOT-23-6

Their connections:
/3V3: R214.1, R215.1, R216.1, R217.1, R218.1, R219.1; also elsewhere on the board
/Controller and ADC/CTRL_USB_CC1: J202.A5, R204.1
/Controller and ADC/CTRL_USB_CC2: J202.B5, R205.1
/Controller and ADC/CTRL_USB_DM: R206.1, U208.6
/Controller and ADC/CTRL_USB_DM_CONN: J202.A7, J202.B7, U208.1
/Controller and ADC/CTRL_USB_DM_MCU: R206.2; also elsewhere on the board
/Controller and ADC/CTRL_USB_DP: R207.1, U208.4
/Controller and ADC/CTRL_USB_DP_CONN: J202.A6, J202.B6, U208.3
/Controller and ADC/CTRL_USB_DP_MCU: R207.2; also elsewhere on the board
/Controller and ADC/CTRL_USB_SHIELD: C234.1, J202.S1, R210.1
/Controller and ADC/CTRL_USB_VBUS: J202.A4, J202.A9, J202.B4, J202.B9, R208.1, U208.5
/Controller and ADC/CTRL_USB_VBUS_SENSE: R208.2, R209.1; also elsewhere on the board
/Controller and ADC/SVC_CELL1_SEL_N: R214.2, SW201.2
/Controller and ADC/SVC_CELL2_SEL_N: R215.2, SW201.3
/Controller and ADC/SVC_CELL3_SEL_N: R216.2, SW201.4
/Controller and ADC/SVC_CELL4_SEL_N: R217.2, SW201.5
/Controller and ADC/SVC_CELL5_SEL_N: R218.2, SW201.6
/Controller and ADC/SVC_CELL6_SEL_N: R219.2, SW201.7
/Controller and ADC/SVC_USB_CC1: J203.A5, R211.1
/Controller and ADC/SVC_USB_CC2: J203.B5, R212.1
/Controller and ADC/SVC_USB_DM_CONN: J203.A7, J203.B7, U209.1, U209.6
/Controller and ADC/SVC_USB_DP_CONN: J203.A6, J203.B6, U209.3, U209.4
/Controller and ADC/SVC_USB_GND: C235.2, J203.A1, J203.A12, J203.B1, J203.B12, R211.2, R212.2, R213.2, U209.2
/Controller and ADC/SVC_USB_SHIELD: C235.1, J203.S1, R213.1
/Controller and ADC/SVC_USB_VBUS: J203.A4, J203.A9, J203.B4, J203.B9, U209.5
/DGND: C234.2, J202.A1, J202.A12, J202.B1, J202.B12, R204.2, R205.2, R209.2, R210.2, SW201.1, U208.2; also elsewhere on the board
/M1_BATN: C1130.2; also elsewhere on the board
/M1_BATP: C1130.1; also elsewhere on the board
/M2_BATN: C1230.2; also elsewhere on the board
/M2_BATP: C1230.1; also elsewhere on the board
/M3_BATN: C1330.2; also elsewhere on the board
/M3_BATP: C1330.1; also elsewhere on the board
/M4_BATN: C1430.2; also elsewhere on the board
/M4_BATP: C1430.1; also elsewhere on the board
/M5_BATN: C1530.2; also elsewhere on the board
/M5_BATP: C1530.1; also elsewhere on the board
/M6_BATN: C1630.2; also elsewhere on the board
/M6_BATP: C1630.1; also elsewhere on the board

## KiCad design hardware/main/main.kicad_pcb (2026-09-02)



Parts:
AE1: Antenna; Texas_SWRA416_868MHz_915MHz
C1, C2, C3, C17, C22, C23, C33, C34, C37, C38, C39, C40, C42: 4.7uF; C_0805_2012Metric
C4, C5: 18pF; C_0402_1005Metric
C6, C9, C12, C13, C14, C15, C18, C19, C20, C21, C30, C31, C32, C35, C36, C41: 100pF; C_0201_0603Metric
C7, C8: 10uF; C_0805_2012Metric
C10, C26, C27, C28: 0.1uF; C_0201_0603Metric
C11: 220pF; C_0402_1005Metric
C16: 2.56pF; C_0201_0603Metric
C24, C25: 8pF; C_0402_1005Metric
C29: 10mF; CP_Radial_D5.0mm_P2.50mm
D1: White; LED_0201_0603Metric
D2: Blue; LED_0201_0603Metric
IC1: ICM-42688-P; IIM42352; Manufacturer_Part_Number ICM-42688-P; Mouser Part Number 410-ICM-42688-P
IC2: PAM2306DYPAA; SON45P300X300X80-13N; Manufacturer_Part_Number PAM2306DYPAA; Mouser Part Number 621-PAM2306DYPAA
IC3: CC1121RHBR; QFN50P500X500X100-33N-D; Manufacturer_Part_Number CC1121RHBR; Mouser Part Number 595-CC1121RHBR
IC4: CC1190RGVR; QFN65P400X400X100-17N-D; Manufacturer_Part_Number CC1190RGVR; Mouser Part Number 595-CC1190RGVR
IC5: TXE8116DGSR; SOP50P490X110-24N; Manufacturer_Part_Number TXE8116DGSR
IC6, IC7, IC8, IC9, IC10: PE64906B-Z; QFN50P200X200X60-11N-D; Manufacturer_Part_Number PE64906B-Z; Mouser Part Number 81-PE64906B-Z
J1: USB-C; PinHeader_1x04_P2.54mm_Vertical
J2: Conn_01x08_Pin; PinHeader_2x04_P1.27mm_Vertical
J3: Conn_01x03_Pin; PinHeader_1x03_P2.54mm_Vertical
J4: Conn_01x09; PinHeader_1x09_P2.54mm_Vertical
J5, J7, J8, J9, J10: Conn_01x08_Pin; PinHeader_1x08_P1.27mm_Vertical
J6: Conn_01x01; SolderWire-0.5sqmm_1x01_D0.9mm_OD2.3mm
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

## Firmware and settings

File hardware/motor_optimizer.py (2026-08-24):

# ============================================================
# MOTOR DESIGN OPTIMIZER — ITERATIVE DEEPENING
# Uses real pyleecan magnetics analysis and progressive refinement
# ============================================================

import itertools as it
import json
import math
import sys
from multiprocessing import Pool, cpu_count
from ssl import HAS_ALPN

import numpy as np
from scipy.optimize import fsolve
from scipy.sparse import lil_matrix
from scipy.sparse.linalg import spsolve

# ============================================================
# OPTIMIZATION PARAMETERS
# ============================================================
MAGNET_TEMP_LIMIT = 120.0
TEMP_SAFETY_MARGIN = 5.0
MAX_REFINEMENT_ITERATIONS = 256
INITIAL_DIVISION_COUNT = 8192  # Coarse-to-fine divisions
MAX_EVALUATIONS_PER_REFINEMENT = 320000  # Limit evaluations per refinement level

# ============================================================
# SPEED OPTIMIZATION PARAMETERS
# ============================================================
# Thermal FEM resolution adapts with refinement level
# Early iterations use coarse resolution for speed, late iterations use fine resolution
THERMAL_FEM_RESOLUTION_MIN = (10, 15)  # (Nr, Nz) coarse: 20 radial, 30 axial
THERMAL_FEM_RESOLUTION_MAX = (60, 90)  # (Nr, Nz) fine: 40 radial, 60 axial

# Always use pyleecan (not analytical fallback)
USE_PYLEECAN = True

# Number of coupling iterations for magnetomechanical feedback
COUPLING_ITERATIONS = 12  # Reduced from 3 for speed, damping handles convergence

# Threshold-based early rejection (skip obviously bad designs)
# These thresholds allow early exit to save computation
RATED_SPEED_RPM = 12000.0  # design-point speed for large prop (documented in requirements.json)
COPPER_LOSS_MAX_PERCENT = 0.5  # reject designs with copper loss above 50 percent of electrical power
TEMP_ABSOLUTE_MAX = 170.0  # deg C absolute winding temperature rejection limit
TARGET_EFFICIENCY = 0.9  # Target 90% efficiency

# Enable multiprocessing (set to True to use parallel evaluation)
USE_MULTIPROCESSING = True
NUM_WORKERS = min(cpu_count() - 1, 8)  # Use all but one CPU, max 8 workers

# ============================================================
# BASE DESIGN PARAMETERS (module level so tools can import them)
# ============================================================
BASE_PARAMS = {
    # FIXED PARAMETERS (cannot change)
    "voltage_dc": 50.4,  # 12S LiPo fully charged (44.4 V nominal) per REV_B_ARCHITECTURE.md
    "I_continuous": 60.0,  # per REV_B_ARCHITECTURE.md: 60 A continuous design current per motor channel
    "I_burst": 90.0,  # burst limited by ESC cell +/-140 A linear sense range and thermal duty
    "wire_resistivity": 2.72e-8,  # Copper @ 20°C
    "Rext": 25.5,
    "T_ambient": 45.0,
    # Material properties (FIXED)
    "steel_grade": "M330-35A",
    "k_copper": 380.0,
    "k_steel": 25.0,
    "off_center_load_pct": 0.1,  # 10% off-center load to simulate propeller thrust effects
    # VARIABLE PARAMETERS (optimized)
    "Rint": 40.5,
    "Rrotor_ext": 40.0,  # Will be overridden: Rrotor_ext = Rint - 0.5
    "Rshaft": 2.0,
    "magnet_thickness": 4.0,
    "motor_length": 55.0,
    "pole_pairs": 7,
    "stator_slots": 12,  # Will be forced to integer
    "magnet_Br": 1.2,
    "h_conv": 40.0,
    "slot_opening": 2.5,
    "wire_diameter": 1.0,  # Wire diameter [mm] — fill factor is DERIVED from this
    "parallel_strands": 4,  # parallel strands per turn (hand-wound bundles)
}

# ============================================================
# MATERIAL PROPERTIES & THERMAL/MECHANICAL DATA
# ============================================================
MATERIAL_PROPS = {
    "copper": {
        "density": 8960,  # kg/m³
        "E_modulus": 110e9,  # Pa (Young's modulus)
        "yield_strength": 200e6,  # Pa (annealed copper)
        "CTE": 16.5e-6,  # /°C (coefficient of thermal expansion)
        "max_stress_safety_factor": 2.0,  # Safety factor for yield
    },
    "steel_M330": {  # M330-35A electrical steel
        "density": 7850,  # kg/m³
        "E_modulus": 210e9,  # Pa
        "yield_strength": 400e6,  # Pa
        "CTE": 12.0e-6,  # /°C
        "max_stress_safety_factor": 2.5,
        "saturation_B": 2.0,  # Tesla (saturation flux density)
    },
    "magnet_N45SH": {
        "density": 7450,  # kg/m³
        "CTE": 5.0e-6,  # /°C (lower than steel)
        "max_compression_stress": 150e6,  # Pa (max compressive)
        "demag_T_coefficient": -0.11,  # %/°C (remanence temp coefficient)
    },
}

# ============================================================
# CONSTRAINED & VARIABLE PARAMETERS
# ============================================================
# FIXED (cannot modify):
# - voltage_dc
# - I_continuous, I_burst
# - wire_resistivity
# - steel_grade, magnet grade properties
# - Rext (external radius)
# - T_ambient
# - fill_factor

# VARIABLE (can be optimized):
# NOTE: Rrotor_ext is derived from Rint (always = Rint - 0.5mm)
VARIABLE_PARAMS = {
    "Rint": (8.0, 25.0),  # stator inner radius [mm]
    "Rshaft": (2.0, 4.0),  # shaft radius [mm]
    "magnet_thickness": (1.5, 8.0),  # magnet thickness [mm]
    "motor_length": (30.0, 80.0),  # motor stack length [mm]
    "pole_pairs": (4, 12),  # integer, pole pairs
    "stator_slots": (9, 24),  # integer, slot count
    "magnet_Br": (1.0, 1.35),  # remanence [T]
    "h_conv": (20.0, 100.0),  # convection coefficient [W/m²K]
    "slot_opening": (1.5, 4.0),  # slot opening width [mm]
    "wire_diameter": (0.1, 3.5),  # wire diameter [mm] — fill factor derived from this
    "parallel_strands": (1, 8),  # parallel strands per turn (integer)
}

# ============================================================
# CORE SIMULATION FUNCTIONS
# ============================================================

# Winding calculation cache to avoid recomputing identical designs
_WINDING_CACHE = {}


def is_valid_winding_topology(slots, pole_pairs):
    """
    Check whether a slot/pole combination supports a manufacturable 3-phase
    winding: either integer-slot distributed or fractional-slot concentrated
    (FSCW). Both are standard for high-performance outrunners.

    Rules (all must hold):
      - slots divisible by 3 (balanced 3-phase)
      - slots >= 6 (minimum 2 coils per phase belt)
      - gcd(slots, poles) == 1 for FSCW (q < 1) or gcd(slots, poles) == poles
        for integer-slot distributed designs; intermediate gcd values create
        unbalanced phase EMFs unless a special coil pattern is used
      - winding factor sanity: slots/poles ratio between 0.25 and 3

    Returns True if valid, False otherwise.
    """
    if slots < 6:
        return False
    if slots % 3 != 0:
        return False
    poles = 2 * int(pole_pairs)
    if poles < 2:
        return False
    ratio = slots / poles
    if not (0.25 <= ratio <= 3.0):
        return False
    # Balanced-winding criterion using the unit machine:
    # divide slot and pole counts by t = gcd(slots, poles); the winding is
    # balanced when the unit machine still has an integer number of coils per
    # phase ((slots/t) % 3 == 0). This accepts every mainstream drone/RC
    # combination: 9N6P, 9N12P, 12N8P, 12N10P, 12N14P, 24N28P, etc.
    t = math.gcd(int(slots), poles)
    unit_slots = int(slots) // t
    if unit_slots % 3 != 0:
        return False
    return True


def _get_closest_valid_winding(original_slots, original_poles):
    """Return the closest (slots, pole_pairs) inside declared bounds that
    satisfies is_valid_winding_topology. Never raises; falls back to the
    known-good 12N14P outrunner combination if nothing else fits."""
    original_slots = int(round(original_slots))
    original_poles = int(round(original_poles))
    slot_bounds = VARIABLE_PARAMS["stator_slots"]
    pole_bounds = VARIABLE_PARAMS["pole_pairs"]

    best = None
    best_dist = None
    for slots in range(slot_bounds[0], slot_bounds[1] + 1):
        for pp in range(pole_bounds[0], pole_bounds[1] + 1):
            if not is_valid_winding_topology(slots, pp):
                continue
            dist = abs(original_slots - slots) + abs(original_poles - pp)
            if best_dist is None or dist < best_dist:
                best_dist = dist
                best = (slots, pp)

    if best is None:
        # Guaranteed-valid fallback within bounds
        best = (12, 7) if is_valid_winding_topology(12, 7) else (9, 2)
        # ensure validity of final fallback
        if not is_valid_winding_topology(best[0], best[1]):
            for s in range(6, 60):
                for q in range(1, 20):
                    if is_valid_winding_topology(s, q):
                        best = (s, q)
                        break
                if is_valid_winding_topology(best[0], best[1]):
                    break
    return best


def compute_winding_params(p):
    """
    Calculate winding parameters and copper losses.

    Wire diameter is an input parameter; fill factor is DERIVED from it.
    This models the fact that wire gauge is a discrete design choice
    that determines actual slot fill.

    Results are cached since winding depends only on geometry + wire diameter.
    """
    # Cache key: winding only depends on these geometric parameters
    cache_key = (
        p["Rext"],
        p["Rint"],
        p["motor_length"],
        p["stator_slots"],
        p["wire_diameter"],
        p.get("parallel_strands", 1),
        p["I_continuous"],
        p["I_burst"],
        p["wire_resistivity"],
    )
    # if cache_key in _WINDING_CACHE:
    #     return _WINDING_CACHE[cache_key]

    # Calculate (if not cached)
    result = _compute_winding_params_impl(p)
    _WINDING_CACHE[cache_key] = result
    return result


def _compute_winding_params_impl(p):
    """Internal implementation of winding parameter calculation."""
    Rext = p["Rext"] * 1e-3
    Rint = p["Rint"] * 1e-3
    L = p["motor_length"] * 1e-3
    slots = p["stator_slots"]
    wire_diameter = p["wire_diameter"] * 1e-3  # Convert mm to meters
    n_strands = int(p.get("parallel_strands", 1))
    if n_strands < 1:
        return None

    # Insulation model: smaller wires have relatively more insulation overhead
    # Typical enameled copper wire: insulation thickness scales with wire diameter
    # Formula: insulation_thickness = a + b * wire_diameter
    # where a accounts for base coating, b is proportional scaling
    # For enameled wire: typical range is 0.05-0.15mm depending on grade

    # Insulation thickness model (meters)
    # Base coating: ~0.03mm, plus proportional scaling
    insulation_thickness = 0.00003 + 0.15 * wire_diameter  # meters

    # Bare copper conductor diameter (core)
    conductor_diameter = (
        wire_diameter - 2 * insulation_thickness
    )  # Subtract insulation from both sides

    # Validate: conductor must be positive
    if conductor_diameter <= 0:
        return None  # Invalid wire size combination

    # Conductor cross-sectional area (copper only), all parallel strands
    conductor_area_single = n_strands * np.pi * (conductor_diameter / 2) ** 2

    # Total wire cross-sectional area (including insulation)
    wire_area_total = np.pi * (wire_diameter / 2) ** 2

    # Insulation area per wire
    insulation_area_per_wire = wire_area_total - conductor_area_single
    slots = 1 if slots == 0 else slots
    # Calculate slot area (full annular sector) — treat as parallelogram
    tooth_angle = 2 * np.pi / slots
    slot_area_full = 1e-20 + 0.5 * (Rext**2 - Rint**2) * tooth_angle

    # Slot geometry as parallelogram:
    # - Radial height: h = Rext - Rint
    # - Tangential width: w = Rint * tooth_angle (average arc length at Rint)
    radial_height = Rext - Rint
    tangential_width = Rint * tooth_angle  # Arc length at inner radius

    # Circle packing in parallelogram (hexagonal close packing)
    # Account for wire insulation thickness: effective spacing is wire_diameter
    # For circles of diameter d in a parallelogram of height h and width w:
    # - Rows along radial direction: n_radial = floor((h - d) / d) + 1
    # - Columns along tangential direction: n_tangential = floor(w / d)
    # - Hexagonal packing efficiency: η ≈ π/(2√3) ≈ 0.9069

    # Bundle diameter: parallel strands twisted together occupy more space
    bundle_diameter_m = wire_diameter * np.sqrt(n_strands)

    # Number of rows (along radial direction) using the bundle diameter
    n_radial = max(
        1, int((radial_height - bundle_diameter_m) / bundle_diameter_m) + 1
    )

    # Number of columns per row (along tangential direction)
    # Account for alternating row offset in hexagonal packing
    n_tangential_odd = max(1, int(tangential_width / bundle_diameter_m))
    n_tangential_even = max(
        1, int((tangential_width - bundle_diameter_m / 2) / bundle_diameter_m)
    )

    # Total wires: alternate between odd and even rows for hexagonal packing
    wires_per_slot = (
        (n_radial // 2 + n_radial % 2) * n_tangential_odd  # Odd rows
        + (n_radial // 2) * n_tangential_even  # Even rows (offset)
    )
    wires_per_slot = max(1, wires_per_slot)

    # Actual fill factor based on CONDUCTOR AREA ONLY (not insulation)
    # Fill factor = (number of wires × conductor area) / slot area
    conductor_area_total = wires_per_slot * conductor_area_single
    actual_fill_factor = conductor_area_total / slot_area_full
    actual_fill_factor = min(
        actual_fill_factor, 0.85
    )  # Cap at realistic maximum (lower for insulation)

    # Note: insulation_area accounts for overhead; smaller wires waste more space
    total_insulation_area = wires_per_slot * insulation_area_per_wire
    insulation_overhead_pct = (total_insulation_area / slot_area_full) * 100

    # Mean turn length (single conductor loop)
    mean_turn_len = np.pi * (Rext + Rint) + 2 * L

    # Total turns = wires per slot × slots
    total_turns = wires_per_slot * slots

    # DC resistance: R = ρ * L / A
    # For 3-phase winding: each phase spans slots/3 slots across the motor
    # All wires in a phase are in SERIES through the winding (not parallel)
    # Therefore: R_phase = ρ * (total length in phase) / (single wire area)
    # NOT divided by area of all slots, which would incorrectly multiply resistance by slot count
    turns_per_phase = total_turns / 3.0
    R_dc = (
        p["wire_resistivity"] * mean_turn_len * turns_per_phase / conductor_area_single
    )

    # Copper losses: P = 3 * I² * R (3-phase Y-connected motor)
    # For Y-connected: I_phase = I_line = I_continuous, so P_total = 3 * I_continuous² * R_dc
    # (Note: Formula was using /√3, which is for delta connection - standard motors use Y)
    P_cu_cont = 3 * (p["I_continuous"]) ** 2 * R_dc
    P_cu_burst = 3 * (p["I_burst"]) ** 2 * R_dc

    results = {
        "slot_area_mm2": slot_area_full * 1e6,
        "wire_area_mm2": (conductor_area_total + total_insulation_area) * 1e6,
        "wire_diameter_mm": wire_diameter * 1e3,
        "wires_per_slot": wires_per_slot,
        "conductor_area_mm2": conductor_area_total * 1e6,
        "fill_factor_actual": actual_fill_factor,  # Derived from wire diameter
        "turns_per_slot": wires_per_slot,  # Wires per slot = turns per slot
        "total_turns": total_turns,
        "R_dc_ohm": R_dc,
        "P_cu_cont_W": P_cu_cont,
        "P_cu_burst_W": P_cu_burst,
    }
    return results


def run_magnetics_pyleecan(p, winding, air_gap_adjustment=0.0, verbose=False):
    """
    Run real magnetics analysis using pyleecan + FEMM
    Falls back to analytical if pyleecan unavailable

    Args:
        air_gap_adjustment: Radial deflection to adjust air gap (mm), negative = gap narrows
    """
    try:
        from pyleecan.Classes.HoleM50 import HoleM50
        from pyleecan.Classes.InputCurrent import InputCurrent
        from pyleecan.Classes.LamSlotLM import LamSlotLM
        from pyleecan.Classes.LamSlotWind import LamSlotWind
        from pyleecan.Classes.MachineSIPMSM import MachineSIPMSM
        from pyleecan.Classes.MagFEMM import MagFEMM
        from pyleecan.Classes.Simulation import Simulation
        from pyleecan.Classes.SlotW29 import SlotW29
        from pyleecan.Classes.Winding import Winding

        stator_slot = SlotW29(
            Zs=p["stator_slots"],
            H0=0.5e-3,
            H1=1.0e-3,
            H2=(p["Rext"] - p["Rint"] - 2.5) * 1e-3,
            W0=p["slot_opening"] * 1e-3,
            W1=3.5e-3,
            W2=4.5e-3,
        )

        # Apply air gap adjustment from mechanical deflection
        Rint_adj = p["Rint"] * 1e-3
        Rrotor_adj = (
            p["Rrotor_ext"] + air_gap_adjustment * 1e-3
        ) * 1e-3  # Convert mm to m for adjustment

        stator = LamSlotWind(
            Rint=Rint_adj,
            Rext=p["Rext"] * 1e-3,
            L1=p["motor_length"] * 1e-3,
            slot=stator_slot,
            winding=Winding(qs=3, p=p["pole_pairs"], Ntcoil=winding["turns_per_slot"]),
        )

        rotor_hole = HoleM50(
            Zh=p["pole_pairs"] * 2,
            W0=0.005,
            W1=0.004,
            W2=0.010,
            W3=0.002,
            W4=0.002,
            H0=0.001,
            H1=0.0015,
            H2=p["magnet_thickness"] * 1e-3,
            H3=0.001,
            H4=0.0,
        )
        rotor = LamSlotLM(
            Rint=p["Rshaft"] * 1e-3,
            Rext=Rrotor_adj,  # Use deflection-adjusted rotor radius
            L1=p["motor_length"] * 1e-3,
            hole=[rotor_hole],
        )

        machine = MachineSIPMSM(stator=stator, rotor=rotor, name="drone_motor_opt")

        simu = Simulation(
            machine=machine,
            input=InputCurrent(
                Id_ref=0,
                Iq_ref=p["I_continuous"],
                Na_tot=2048,
                Nt_tot=32,
                felec=500.0,
            ),
            mag=MagFEMM(
                is_periodicity_a=True,
                is_periodicity_t=True,
                nb_worker=4,
                is_fast_draw=True,
                is_sliding_band=True,
                is_calc_torque_energy=True,
                T_mag=p["T_ambient"] + 25,
            ),
        )

        out = simu.run()
        Tem_vals = out.mag.Tem.values
        Tem_avg = float(np.mean(Tem_vals))
        Tem_rip = float(out.mag.Tem_rip_norm)
        time_vec = out.mag.Tem.axes[0].values

        if verbose:
            print(
                f"    [FEMM] Torque: {Tem_avg:.3f}Nm, Ripple: {Tem_rip * 100:.1f}%",
                flush=True,
            )

        return {
            "Tem_avg": Tem_avg,
            "Tem_rip": Tem_rip,
            "Tem_vals": Tem_vals,
            "time_vec": time_vec,
            "is_pyleecan": True,
        }

    except Exception as e:
        # Fallback to analytical
        if verbose:
            print(f"    [Analytical fallback] {type(e).__name__}", flush=True)

        Tem_avg = _analytical_torque(p, winding)

        Nt = 256
        theta = np.linspace(0, 2 * np.pi, Nt)
        ripple = 0.04 * Tem_avg * np.cos(p["stator_slots"] * theta)
        Tem_vals = Tem_avg + ripple

        return {
            "Tem_avg": Tem_avg,
            "Tem_rip": 0.04,
            "Tem_vals": Tem_vals,
            "time_vec": theta,
            "is_pyleecan": False,
        }
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

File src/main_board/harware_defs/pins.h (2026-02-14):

#include "pico-sdk/src/rp2350/hardware_structs/include/hardware/structs/io_bank0.h"
#include <stdint.h>
#include <stdbool.h>
#ifndef PINS_H
#define PINS_H

#define GPIO_FUNC_HSTX  0, ///< Select HSTX as GPIO pin function
#define GPIO_FUNC_SPI  1, ///< Select SPI as GPIO pin function
#define GPIO_FUNC_UART  2, ///< Select UART as GPIO pin function
#define GPIO_FUNC_I2C 3, ///< Select I2C as GPIO pin function
#define GPIO_FUNC_PWM  4, ///< Select PWM as GPIO pin function
#define GPIO_FUNC_SIO  5, ///< Select SIO as GPIO pin function
#define GPIO_FUNC_PIO0  6, ///< Select PIO0 as GPIO pin function
#define GPIO_FUNC_PIO1  7, ///< Select PIO1 as GPIO pin function
#define GPIO_FUNC_PIO2  8, ///< Select PIO2 as GPIO pin function
#define GPIO_FUNC_GPCK 9, ///< Select GPCK as GPIO pin function
#define GPIO_FUNC_XIP_CS1  9, ///< Select XIP CS1 as GPIO pin function
#define GPIO_FUNC_CORESIGHT_TRACE  9, ///< Select CORESIGHT TRACE as GPIO pin function
#define GPIO_FUNC_USB  10, ///< Select USB as GPIO pin function
#define GPIO_FUNC_UART_AUX  11, ///< Select UART_AUX as GPIO pin function
#define GPIO_FUNC_NULL  0x1f, ///< Select NULL as GPIO pin function

uint8_t global_pin_func_map[48] = {
    GPIO_FUNC_NULL, // GPIO0
    GPIO_FUNC_NULL, // GPIO1
    GPIO_FUNC_NULL, // GPIO2
    GPIO_FUNC_NULL, // GPIO3
    GPIO_FUNC_NULL, // GPIO4
    GPIO_FUNC_NULL, // GPIO5
    GPIO_FUNC_NULL, // GPIO6
    GPIO_FUNC_NULL, // GPIO7
    GPIO_FUNC_NULL, // GPIO8
    GPIO_FUNC_NULL, // GPIO9
    GPIO_FUNC_NULL, // GPIO10
    GPIO_FUNC_NULL, // GPIO11
    GPIO_FUNC_NULL, // GPIO12
    GPIO_FUNC_NULL, // GPIO13
    GPIO_FUNC_NULL, // GPIO14
    GPIO_FUNC_NULL, // GPIO15
    GPIO_FUNC_NULL, // GPIO16
    GPIO_FUNC_NULL, // GPIO17
    GPIO_FUNC_NULL, // GPIO18
    GPIO_FUNC_NULL, // GPIO19
    GPIO_FUNC_NULL, // GPIO20
    GPIO_FUNC_NULL, // GPIO21
    GPIO_FUNC_NULL, // GPIO22
    GPIO_FUNC_NULL, // GPIO23
    GPIO_FUNC_NULL, // GPIO24
    GPIO_FUNC_NULL, // GPIO25
    GPIO_FUNC_NULL, // GPIO26
    GPIO_FUNC_NULL, // GPIO27
    GPIO_FUNC_NULL, // GPIO28
    GPIO_FUNC_NULL, //GPIO29 
    GPIO_FUNC_NULL, //GPIO30 
    GPIO_FUNC_NULL,  //GPIO31
    GPIO_FUNC_NULL, //GPIO32
    GPIO_FUNC_NULL, //GPIO33
    GPIO_FUNC_NULL, //GPIO34
    GPIO_FUNC_NULL, //GPIO35
    GPIO_FUNC_NULL, //GPIO36
    GPIO_FUNC_NULL, //GPIO37
    GPIO_FUNC_NULL, //GPIO38
    GPIO_FUNC_NULL, //GPIO39
    GPIO_FUNC_NULL, //GPIO40
    GPIO_FUNC_NULL, //GPIO41
    GPIO_FUNC_NULL, //GPIO42
    GPIO_FUNC_NULL, //GPIO43
    GPIO_FUNC_NULL, //GPIO44
    GPIO_FUNC_NULL, //GPIO45
    GPIO_FUNC_NULL, //GPIO46
    GPIO_FUNC_NULL //GPIO47
};


#define GPIO_PULL_NONE 0
#define GPIO_PULL_UP 1
#define GPIO_PULL_DOWN 2
#define use_schmidt_trigger true
uint8_t global_pin_pullup[48] = {
    GPIO_PULL_NONE, // GPIO0
    GPIO_PULL_NONE, // GPIO1
    GPIO_PULL_NONE, // GPIO2
    GPIO_PULL_NONE, // GPIO3
    GPIO_PULL_NONE, // GPIO4
    GPIO_PULL_NONE, // GPIO5
    GPIO_PULL_NONE, // GPIO6
    GPIO_PULL_NONE, // GPIO7
    GPIO_PULL_NONE, // GPIO8
    GPIO_PULL_NONE, // GPIO9
    GPIO_PULL_NONE, // GPIO10
    GPIO_PULL_NONE, // GPIO11
    GPIO_PULL_NONE, // GPIO12
    GPIO_PULL_NONE, // GPIO13
    GPIO_PULL_NONE, // GPIO14
    GPIO_PULL_NONE, // GPIO15
    GPIO_PULL_NONE, // GPIO16
    GPIO_PULL_NONE, //GPIO17 
    GPIO_PULL_NONE, //GPIO18
    GPIO_PULL_NONE, //GPIO19
    GPIO_PULL_NONE, //GPIO20
    GPIO_PULL_NONE, //GPIO21
    GPIO_PULL_NONE, //GPIO22
    GPIO_PULL_NONE, //GPIO23
    GPIO_PULL_NONE, //GPIO24
    GPIO_PULL_NONE, //GPIO25
    GPIO_PULL_NONE, //GPIO26
    GPIO_PULL_NONE, //GPIO27
    GPIO_PULL_NONE, //GPIO28
    GPIO_PULL_NONE, //GPIO29
    GPIO_PULL_NONE, //GPIO30
    GPIO_PULL_NONE, //GPIO31
    GPIO_PULL_NONE, //GPIO32
    GPIO_PULL_NONE, //GPIO33
    GPIO_PULL_NONE, //GPIO34
    GPIO_PULL_NONE, //GPIO35
    GPIO_PULL_NONE, //GPIO36
    GPIO_PULL_NONE, //GPIO37
    GPIO_PULL_NONE, //GPIO38
    GPIO_PULL_NONE, //GPIO39
    GPIO_PULL_NONE, //GPIO40
    GPIO_PULL_NONE, //GPIO41
    GPIO_PULL_NONE, //GPIO42
    GPIO_PULL_NONE, //GPIO43
    GPIO_PULL_NONE, //GPIO44
    GPIO_PULL_NONE, //GPIO45
    GPIO_PULL_NONE, //GPIO46
    GPIO_PULL_NONE //GPIO47
};
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

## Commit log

2026-02-15 rewrote spi, had ai copy into many other functions, reworked gpio a little
    [pins.h]
2026-02-15 Refactor dynamic clock speed management with peripheral stability tests and adherence to P10
    [overclocking.c, pins.h]
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2026-02-18 magnetic optimiser for motor
    [motor_design_results_optimized.json]
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2026-02-24 motor optimizer headaches, pausing here for now to finish the code
    [motor_design_results_optimized.json]
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2026-03-18 trying to fix lsm6
    [pins.h]
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2026-05-09 Auto-sync ESC PCB 2026-05-09 17:28:29
    [esc.kicad_pcb]
2026-05-09 Auto-sync ESC PCB 2026-05-09 18:43:14
    [esc.kicad_pcb]
2026-05-09 Auto-sync ESC PCB 2026-05-09 23:58:51
    [esc.kicad_pcb]
2026-05-10 Auto-sync ESC PCB 2026-05-10 17:41:22
    [esc.kicad_pcb]
2026-05-10 Auto-sync ESC PCB 2026-05-10 18:37:37
    [esc.kicad_pcb]
2026-05-10 Auto-sync ESC PCB 2026-05-10 18:38:28
    [esc.kicad_pcb]
2026-05-10 Auto-sync ESC PCB 2026-05-10 18:41:06
    [esc.kicad_pcb]
2026-05-10 Auto-sync ESC PCB 2026-05-10 18:47:47
    [esc.kicad_pcb]
2026-05-10 Auto-sync ESC PCB 2026-05-10 21:44:25
    [esc.kicad_pcb]
2026-05-10 Auto-sync ESC PCB 2026-05-10 22:44:06
    [esc.kicad_pcb]
2026-05-10 Auto-sync ESC PCB 2026-05-10 22:44:23
    [esc.kicad_pcb]
2026-05-10 Auto-sync ESC PCB 2026-05-10 22:59:24
    [esc.kicad_pcb]
2026-05-10 Restore ESC auto-sync scripts and startup launcher
    [esc.kicad_pcb]
2026-05-10 Auto-sync ESC PCB 2026-05-11 00:44:28
    [esc.kicad_pcb]
2026-05-10 Auto-sync ESC PCB 2026-05-11 00:46:01
    [esc.kicad_pcb]
2026-05-10 Auto-sync ESC PCB 2026-05-11 00:51:51
    [esc.kicad_pcb]
2026-05-10 Auto-sync ESC PCB 2026-05-11 02:34:28
    [esc.kicad_pcb]
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2026-05-11 Auto-sync ESC PCB 2026-05-12 00:58:57
    [esc.kicad_pcb]
2026-05-13 Auto-sync ESC PCB 2026-05-13 22:00:56
    [esc.kicad_pcb]
2026-05-13 Auto-sync ESC PCB 2026-05-13 22:13:51
    [esc.kicad_pcb]
2026-05-13 Auto-sync ESC PCB 2026-05-13 22:14:24
    [esc.kicad_pcb]
2026-05-13 Auto-sync ESC PCB 2026-05-13 22:28:48
    [esc.kicad_pcb]
2026-05-13 Auto-sync ESC PCB 2026-05-13 22:55:33
    [esc.kicad_pcb]
2026-05-13 Auto-sync ESC PCB 2026-05-13 22:55:45
    [esc.kicad_pcb]
2026-05-13 Auto-sync ESC PCB 2026-05-13 22:56:11
    [esc.kicad_pcb]
2026-05-13 Auto-sync ESC PCB 2026-05-13 22:57:08
    [esc.kicad_pcb]
2026-05-13 Auto-sync ESC PCB 2026-05-13 23:09:05
    [esc.kicad_pcb]
2026-05-13 Auto-sync ESC PCB 2026-05-13 23:15:14
    [esc.kicad_pcb]
2026-05-13 Auto-sync ESC PCB 2026-05-13 23:17:03
    [esc.kicad_pcb]
2026-05-13 Auto-sync ESC PCB 2026-05-13 23:25:39
    [esc.kicad_pcb]
2026-05-14 Auto-sync ESC PCB 2026-05-14 14:57:42
    [esc.kicad_pcb]
2026-05-14 Auto-sync ESC PCB 2026-05-14 18:54:00
    [esc.kicad_pcb]
2026-05-14 Auto-sync ESC PCB 2026-05-14 19:03:09
    [esc.kicad_pcb]
2026-05-14 Auto-sync ESC PCB 2026-05-14 19:41:35
    [esc.kicad_pcb]
2026-05-14 Auto-sync ESC PCB 2026-05-14 19:43:25
    [esc.kicad_pcb]
2026-05-14 Auto-sync ESC PCB 2026-05-14 19:44:52
    [esc.kicad_pcb]
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2026-08-24 motor: fix disabled safety gates and release manufacturer package
    Optimizer audit found rejection thresholds scaled by 1e92 (disabled), a corrupted thermal FEM matrix (k/1e-20 coefficients) that produced the bogus 467C result, a winding validator that rejected all standard outrunner topologies including 12N14P, inverted bounds logic in the closest-winding search, and no overspeed check. All safety constraints are now hard gates with tests: thermally/mechanically/overspeed/airgap/winding/bounds each reject unsafe designs.
    Electrical contract re-anchored to repo sources of truth: 12S LiPo 44.4V nominal / 50.4V max per REV_B_ARCHITECTURE.md; six-cell refers to the six ESC motor cells, not chem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
    [BOM.csv, efficiency_map.csv, motor_interface.json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]
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2026-08-24 esc: add M2-M6 controller strip zones + stitching vias; M4-M6 BATN now 0 unconnected
    [esc_rev_b.kicad_pcb]
2026-08-24 esc: verified clean revert of failed auto-route attempt; boards at best achievable state via scripting
    [controller.kicad_sch, esc_rev_b.kicad_sch, main_rev_b_completed.kicad_pcb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]
2026-08-25 esc: remove isolated F.Cu BATN strips; restore M4-M6 to clean state; no isolated copper
    [esc_rev_b.kicad_pcb]
2026-08-25 main: route CAN_5V/CAN_GND chains to J60-J65 headers and J2/F1/R3; 56->47 unconnected
    [main_rev_b_final.kicad_pcb]
2026-08-25 esc: FreeRouting attempt on ESC board failed (OOM); boards at best scripted state
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2026-08-26 main: FreeRouting signal routing imported (413->62 unrouted signals); cleanup slivers+dangling; 234 unconnected awaiting power zones
    [main_rev_b.kicad_pcb]
2026-08-26 main: power planes (F.Cu+B.Cu GND, In1 3V3, In2 1V1) + 130 via drops + SYS_5V trunk; 234->~70 unconnected
    [main_rev_b.kicad_pcb]
2026-08-26 main: SYS_5V trunk routed obstacle-checked; 0 real violations, 70 unconnected (signal pads remain)
    [main_rev_b.kicad_pcb]
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2026-08-29 main: enforce standard fab rules and clean routed board
    [main.kicad_pcb]
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2026-08-29 Keep ESC programming interface to two USB-C ports
    [controller.kicad_sch, esc_165mm_usb_reconciled.kicad_pcb, esc_rev_b.kicad_pcb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]
2026-08-29 Replace ESC selector with seven-pin active-low control
    [controller.kicad_sch, esc_165mm_usb_reconciled.kicad_pcb, esc_rev_b.kicad_pcb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]
2026-09-02 esc: verify replicated power pours and free mismatched bus pairs
    [esc_rev_b.kicad_pcb]
2026-09-02 esc: replicate hand-routed power copper and free main diff pairs
    [esc_rev_b.before_hand_power_replicate.kicad_pcb, main_rev_b_final.before_diff_pair_ripup.kicad_pcb]
2026-09-10 esc: repack components without physical collisions
    [esc_rev_b.kicad_pcb]
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2026-09-10 revert ESC to front-side-only placement from 325f93b; main board CANL routing + ACT45B pinout fix
    [esc_rev_b.kicad_pcb, interfaces.kicad_sch, main_rev_b_final.kicad_pcb]
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2026-09-12 esc: finish MCU core rail and stitch phase pads
    [esc_rev_b.kicad_pcb]
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2026-09-12 esc: route SWDIO and high-side C gate signals
    [esc_rev_b.kicad_pcb]
2026-09-12 esc: route high-side A and B gate signals
    [esc_rev_b.kicad_pcb]
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2026-09-12 esc: route A and B raw current-sense signals
    [esc_rev_b.kicad_pcb]
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2026-09-13 ESC: compact front placement and restore protected signal routing
    [esc_rev_b.kicad_pcb]
2026-09-13 ESC: route twelve local signals with bidirectional A-star
    [esc_rev_b.kicad_pcb]
2026-09-13 ESC: route ten more support signals with bounded A-star
    [esc_rev_b.kicad_pcb]
2026-09-14 ESC: compact cell lattice and route twelve gate signals
    [esc_rev_b.kicad_pcb]
2026-09-14 ESC: compact buck layout and route quiet signals
    [esc_rev_b.kicad_pcb]
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2026-09-14 esc: replicate compact motor cell and restore USB debug
    [esc_rev_b.kicad_pcb]
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2026-10-30 ci: pin clean-checkout verified native fixtures
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2026-10-30 fix: pin evidence profile in acceptance catalog
2026-10-30 audit source-pinned PCB variants for issue 23
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2026-10-30 fix: parse per-sheet KiCad ERC findings
2026-10-30 fix: measure PCB Edge.Cuts centerline extents
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2026-10-31 pcb: route rev b RF reset on back copper
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2026-11-01 docs: pin independent issue 21 main board DRC snapshot
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2026-11-01 docs: bound GND via clearance search
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2026-11-02 docs: archive rejected RF reset route probe
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2026-11-02 pcb: route HGM and RF reset connections
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2026-11-05 rf: correct port normalization and preserve probe evidence
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2026-11-12 DA-G1: ERC/DRC/parity report for Rev B (DRC 0/0; parity fails: FL50 CAN choke, ESC PWM)
    KiCad 9.0.7, board sha256 b500f5fe.... DRC 0 violations / 0 unconnected.
    ERC 1 warning (FL50 L_Coupled lib_symbol_mismatch). Schematic parity 191:
    161 library-nickname-only footprint IDs, 11 '/' vs '{slash}' no-connect
    names, 4 board-only mounting holes (cosmetic); 6 ESC PWM nets + J60-J65
    present only in the schematic; FL50 pad nets imply windings 1-2/3-4 while
    TDK's ACT45B model gives 1-4/2-3, so the board likely crosses CANH/CANL
    through the choke (owner to confirm land-pattern numbering). Report only;
    no board edits.
2026-11-12 DA-G2: RF path geometry audit — RF lines reference the In1 3V3 plane
    915 MHz and GNSS RF traces (0.35 mm, F.Cu) sit 100% over the In1 /3V3
    zone and 0% over /GND, with F.Cu GND pour 0.25 mm away (grounded
    coplanar). Analytical Z0 51.3 ohm (microstrip) / 52.9 ohm (GCPW, loose
    approximation) -> quoted as ~51-53 ohm; not an EM solve. Report only.

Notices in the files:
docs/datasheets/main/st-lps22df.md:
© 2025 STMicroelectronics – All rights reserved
